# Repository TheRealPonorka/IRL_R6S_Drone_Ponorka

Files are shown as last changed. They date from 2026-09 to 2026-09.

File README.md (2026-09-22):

# Tom Clancy's Rainbow Six: Siege - Recon Drone by Ponorka
Last update: 22/09/2026

This project is inspired by a fictional tool called Recon drone from game Tom Clancy's Rainbow Six: Siege.
I have created a fan page on facebook for this project, where I will post some updates while I am working on it or doing some stuffs with it, here:
https://www.facebook.com/profile.php?id=61594372602997

I have built a similar drone, which was based on another github project https://github.com/hemrobotics/recon-drone and I was wondering: "Can this drone be really a fully operational 2 wheeled remote controlled drone?" This github repo should be the answer for this.

# WIP - Work In Progress
This repo is still in progress. Right now 22/09/2026 the PCB is ready and I am waiting for the supplies so I can build the prototype.
The firmware is mostly ready, but it needs polishing.
Unfortunately, my experience in coding other than PowerShell is HIGHLY LIMITED, so I apologize from everyone who might check the code and see what is happening there :D
So a lot of AI coding will be involved in this project. Sorry to everyone, I am just an enthusiast gamer in this case. In my professional life I am a SysAdmin :D

Slowly but there will be updates here to add the details about this project.

# Make it but don't sell it!
Keep in mind that this is a hobby project and I am giving it available to everyone, who is interested to build this project. So far I am not planning to make money from this and I would be happy to keep this mindset in a same way for everyone.
Don't make a hustle from this project! If you are interested, but you can't build it by yourself, ask someone, give the person all the necessary HW and pay him for the worktime, but do not sell it for profit!
I have applied proper licensing description for this reason.
If you will assemble it, credit my github/facebook fan page properly so others can reach this project as well :)
Thanks for understanding.

# Now the "FUN" Part
Okay, so if you came to this place, you probably want to build your own Recon drone (or maybe just get an inspiration, I don't know, I can't read minds :D ).
I will do my best to explain everything around so the build would be easier to complete for anyone :)

The schematics and Parts
Took me some time to get back to this knowledge, as I did not work on any electronics for several years. I figured out some basic stuffs, which were needed in addition to properly have all the stuffs working together.
As I wanted to add all the possible features what a recon drone have in R6S, I needed think over, what I want to achieve:
1. Self-balancing 2 wheeled robot
2. Camera for reconnaissance
3. LED Spotlight to light up darker places
4. Addressable RGB LED strip with 6 LEDs to replicate the visuals of the drone
5. Operate the entire drone from a single 18650 Li-Po battery cell.
6. Microphone to hear via the web stream what is happening arround. (Unfortunately could not achieve this, so I dropped this feature)

So, how to achieve that?
First we need a microcontroller (MCU) robust enough to handle all the stuffs. After reviewing all the possibilities and cost effectiveness, I decided to go with ESP32-S3 CAM DEVKITC especially from GOOUUU.
For now this is sufficient for everything we need (later on I might rethink the schematics and PCB layout with fully self-built PCB using only the MCU and not the devkit).
For camera module I decided to go with OV3660, as this module has good enough resolution, while keeping the FPS high enough to have a smooth experience.
Early build I planned with omnidirectional microphone module as well, however after further testing this came out as unusable for real time audio stream so I left this idea out of the final build.
The motors I have selected are N20 small geared motors operating on 6V with gear reduction 1:30 and built-in HAL encoder. This gives the drone possibly enough torque and power to balance, while keeping the voltage on lower side (more on it later)
The motor driver is a DRV8833, there is not much to talk about it, it is a sweet spot for this build. Low cost, low power.
The balancing is solved by IMU module BMI270, slotted on the main board.
Now here comes the power consumption part. In my previous attempt to build this drone I was happy to handle everything with only one 18650 LiPo battery cell and I wanted to keep it that way.
I have found a 18650 battery cell shield, which can handle massive current delivery at 5V (up to 3A): https://www.aliexpress.com/item/1005006252337213.html
With this solution I can easily power the ESP32, the LED strip, the motor drivers and the HAL sensors. It might not be able to run for tens of hours, but this solution should be sufficient to handle power delivery for several hours.
The battery shield needed some modifications:
- removed USB-A port
- Removed USB-C charging port and soldered cables for external USB-C connector. This was necessary to add the USB-C charging port on the back of the drone, next to the ON/OFF switch and Wi-Fi antenna.
And if you have a spare 18650 battery cell, you can replace it whenever you need inside chasis. Even though I do not recommend it, as replacement of the battery needs quite some screws to remove. This is something I did not solve in easier way yet.
There was a need to lower voltage from the motors HAL sensors. As they are operating on 5V from the battery shield, but this voltage would fry the MCU, as the MCU operates the GPIO pins with 3.3V. I needed to add a 4-channel bi-polar level shifter, so we don't fry our MCU with 5V input :)
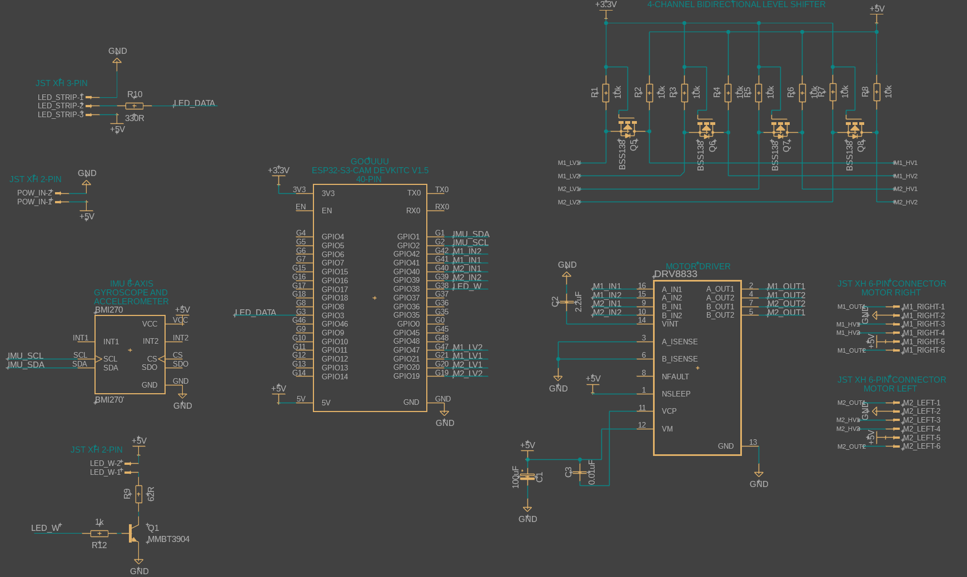
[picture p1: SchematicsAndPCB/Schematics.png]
Schematics


The PCB
After several iterations of how and where the parts should be placed, I finished with this version of 2-layer PCB. The entire PCB size is 45x99.2 mm.

Already ordered PCB from manufacturer
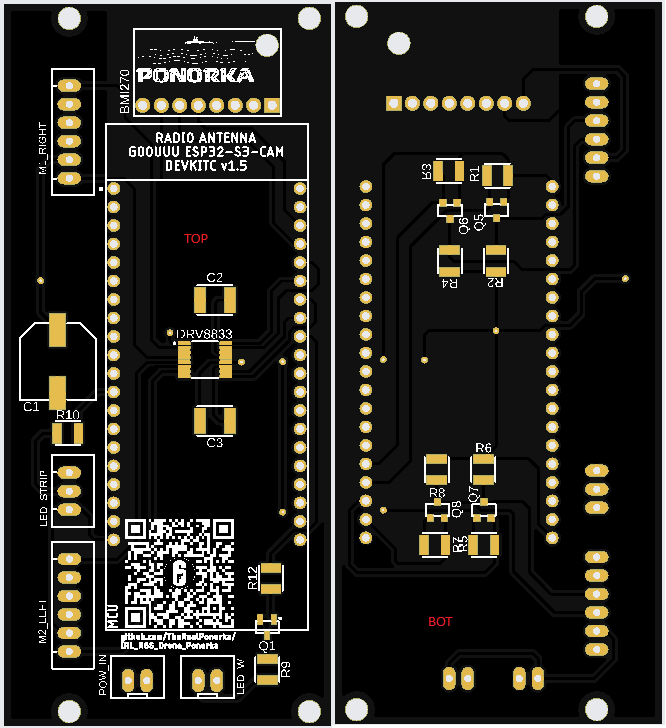
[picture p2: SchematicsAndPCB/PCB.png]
PCB


3D overview of the final board
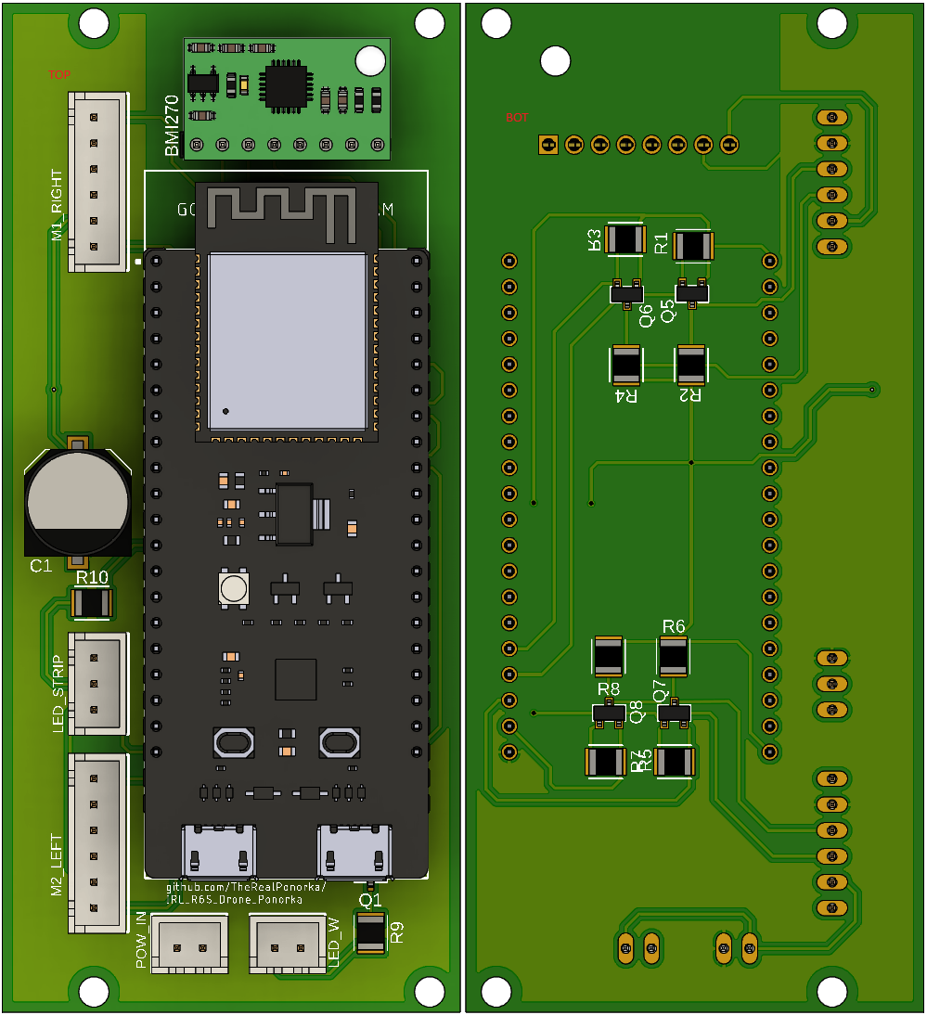
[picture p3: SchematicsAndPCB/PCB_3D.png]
PCB_3D


# The Code
This is where my knowledge is really behind, and if you will review my code later on, you might find a lot of issues with that.
The entire firmware code is based on vide coding in cooperation with Cursor. At the beginning I used Claude Sonnet 4, then I changed it to Cursor Grok 4.6
Right now, the firmware is functioning with these features on test breadboard:
- LED strip is creating the animation of the 6 ARGB LEDs based on the calculation from recorded footage of 30ms from middle to outside and back, default color is GREEN.
- Spotlight high brightness single white LED can be toggled ON/OFF
- Motors are spinning
- IMU is correctly communicating with MCU and based on the tilt it is regulating the motor movement
- MCU Wi-Fi module is correctly generating AP with SSID: "R6_Recone_Drone" and WPA password: "ReconDrone123"
- A basic (so far not modified) webserver is generated by the MCU on IP 192.168.4.1 with camera stream and buttons to operate the drone (move, LED strip color change, LED spotlight toggle, IMU data)

# The Body
I took screenshots from the game and based on it I tried to model out the outside of the drone as accurate as I could.
The body is created from 4 parts:
- TOP
- BOTTOM
- RIGH and LEFT motor/wheel holder
IT IS NOT PERFECTLY ACCURATE.
There were some challenges which I had to solve during initial test prints so it could be printed easier on 3D printer and assemble at the end.
From the front part it looks almost identical to one in the game, however the back I had to change a bit.
The top part on the back is stripped a bit, which I added for the bottom. The reason is to assemble easier the insides: USB-C charging port, Wi-Fi antenna and ON/OFF switch together with the electronics boards inside.
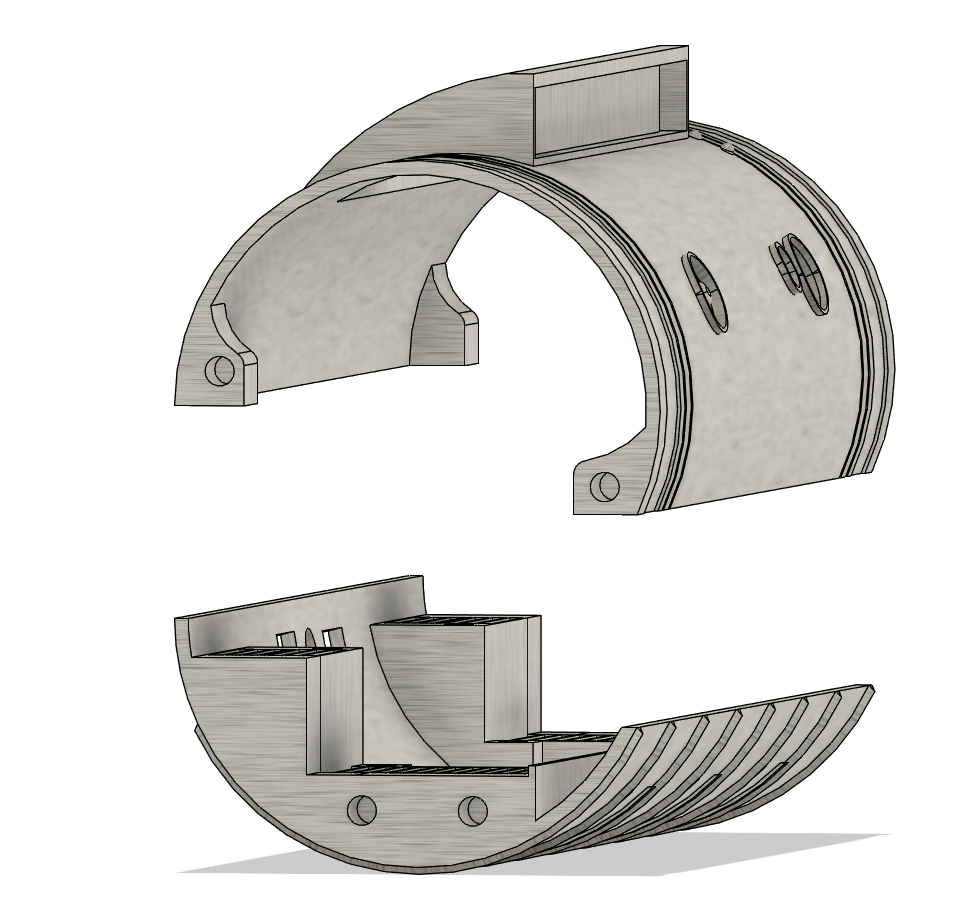
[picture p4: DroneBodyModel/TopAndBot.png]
bodyTopAndBot

The motors I used are the following: https://www.aliexpress.com/item/1005012449655687.html with these specifications selected: "1 to 30, DC 6V A06 Type" and they are screwed in with really small 1.6mm screws
I have created an overengineered stand for this, you can see it on the pictures and the model.

# The test
I know, the breadboard "spaghetti" looks terrifying, but if you follow the schematics, you don't need to be afraid of it :) It is easier than you think!
Anyway, after many attempts, I have finally reached the testing state, where I can (hopefully) confidently say: IT WORKS!

# Next steps
Currently I am waiting for my final PCB (this is my 4th attempt, so my 4th order. I know I f-ed up. I did not start with breadboard testing before I ordered previous PCB attemtps) I have ordered, based on the gerber file you can find in "SchematicsAndPCB"
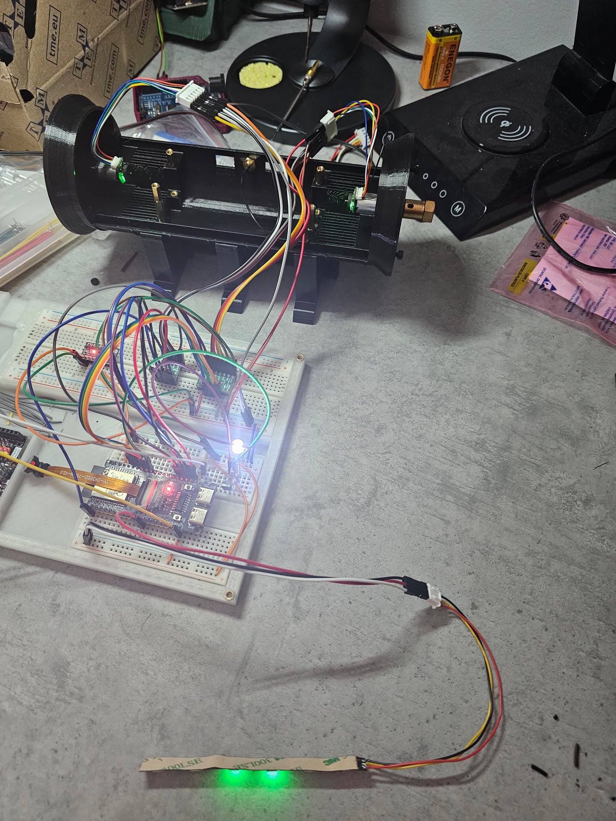
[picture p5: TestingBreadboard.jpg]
Breadboard

Hopefully, once it will arrive and solder all the components (Bill of materials, a.k.a. BOM you can find in "SchematicsAndPCB") it will finally work. Previous (3rd) version was already working, but I connected one motor signal to a PIN, which is used for Wi-Fi, so I had to redo the pinouts a bit.

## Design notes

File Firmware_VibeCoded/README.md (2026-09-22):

# R6 Recon Drone - Rainbow Six: Siege Replica

A fully functional self-balancing camera drone replica inspired by the recon drones from Tom Clancy's Rainbow Six: Siege. Built with ESP32-S3 and featuring a responsive web interface, real-time camera streaming, and advanced control systems.

## 🎯 Features

### Hardware
- **MCU**: ESP32-S3 CAM N16R8 (GOOUUU v1.5) - 16MB Flash, 8MB PSRAM
- **IMU**: BMI270 6-axis sensor for precise balance control
- **Motors**: Dual DRV8833 H-bridge motor controller
- **Camera**: OV3660 with HD 1280x720 default resolution
- **Audio**: INMP441 I2S digital microphone
- **Lighting**: WS2812B RGB LED strip (12 LEDs)
- **Spotlight**: High-power LED with PWM control
- **Encoders**: Quadrature encoders for precise movement tracking

### Software Architecture
- **Dual-Core FreeRTOS**: 
  - Core 0: High-speed IMU/PID balance control at 100Hz
  - Core 1: Web server, camera streaming, LED animations
- **Real-time PID Control**: Advanced balancing algorithms
- **Responsive Web Interface**: Multi-touch support, mobile-optimized
- **Live Camera Streaming**: HD video with configurable settings
- **WiFi Connectivity**: Station mode with AP fallback

### Control Features
- **Movement Controls**: Forward, backward, left, right with smooth acceleration
- **Camera Stream**: Real-time HD video with overlay controls
- **Audio Streaming**: Live microphone feed (when enabled)
- **LED Control**: RGB color picker with animations and patterns
- **Spotlight Control**: Variable brightness white LED
- **Emergency Safety**: Automatic tilt detection and motor cutoff

## 🛠️ Hardware Setup

### Pin Configuration

| Component | Pin Assignment |
|---|---|
| **BMI270 IMU (I2C)** | SCL=1, SDA=2 |
| **DRV8833 Motors** | Motor A: 35,36 / Motor B: 37,38 |
| **Encoders** | Left: 45,46 / Right: 48,21 |
| **INMP441 Microphone** | SCK=41, WS=42, SD=20 |
| **WS2812B LEDs** | Data=3 |
| **Spotlight** | Gate=14 |
| **OV3660 Camera** | SIOD=4, SIOC=5, VSYNC=6, HREF=7, PCLK=13, XCLK=15 |
| **Camera Data** | D0-D7: [11,9,8,10,12,18,17,16] |

### Wiring Diagram
```
ESP32-S3 CAM N16R8
├── I2C Bus (IMU)
│   ├── SCL (GPIO 1) ──→ BMI270 SCL
│   └── SDA (GPIO 2) ──→ BMI270 SDA
├── Motor Control
│   ├── GPIO 35 ──→ DRV8833 Motor A1
│   ├── GPIO 36 ──→ DRV8833 Motor A2  
│   ├── GPIO 37 ──→ DRV8833 Motor B1
│   └── GPIO 38 ──→ DRV8833 Motor B2
├── LED & Lighting
│   ├── GPIO 3 ──→ WS2812B Data In
│   └── GPIO 14 ──→ Spotlight Gate
└── Audio & Sensors
    ├── I2S (GPIO 41,42,20) ──→ INMP441
    └── Encoders (GPIO 45,46,48,21)
```

## 🚀 Quick Start

### 1. PlatformIO Setup
```bash
# Clone the repository
git clone <repository-url>
cd IRL_R6_Drone

# Install PlatformIO (if not already installed)
pip install platformio

# Build the project
pio run

# Upload to ESP32-S3
pio run --target upload

# Monitor serial output
pio device monitor
```

### 2. WiFi Configuration
1. Power on the drone
2. Connect to WiFi network "R6_Drone_Network" (password: "Rainbow6Siege")
3. Or modify `config.h` with your WiFi credentials
4. Access the web interface at the drone's IP address

### 3. Web Interface Access
- **Main Control**: `http://[drone-ip]/`
- **Camera Config**: `http://[drone-ip]/camera-config.html`
- **WebSocket**: `ws://[drone-ip]:81`

## 🎮 Web Interface Guide

### Main Control Interface
- **Camera Stream**: Central HD video feed with overlay controls
- **Movement**: Touch-friendly directional buttons (Forward/Back/Left/Right)
- **Audio**: Microphone toggle in top-right overlay
- **Spotlight**: LED spotlight toggle in bottom-center overlay
- **LED Strip**: Color picker and on/off toggle in bottom-left
- **Fullscreen**: Expand interface to full screen
- **Telemetry**: Real-time sensor data display

### Camera Configuration
- **Resolution**: From 96x96 to 1920x1080 (FHD)
- **Quality**: JPEG compression settings
- **Image Enhancement**: Brightness, contrast, saturation
- **Special Effects**: Filters and color adjustments
- **Presets**: Quick configurations (Recon, Night Vision, High Quality, Performance)

### Control Commands
```javascript
// WebSocket command format
{
  "command": "forward|backward|left|right|microphone|spotlight|ledstrip|ledcolor",
  "value": true|false|"255,140,0",
  "timestamp": 1234567890
}
```

## 🔧 Configuration

### PID Tuning
Edit `config.h` to adjust PID parameters:
```cpp
// Balance PID (pitch control)
#define PID_BALANCE_KP 30.0f
#define PID_BALANCE_KI 0.5f
#define PID_BALANCE_KD 0.8f

// Velocity PID (speed control)  
#define PID_VELOCITY_KP 2.0f
#define PID_VELOCITY_KI 0.1f
#define PID_VELOCITY_KD 0.05f
```

### Camera Settings
```cpp
#define CAMERA_FRAME_SIZE FRAMESIZE_HD    // 1280x720
#define CAMERA_QUALITY 10                 // JPEG quality
#define CAMERA_FB_COUNT 2                 // Frame buffers
```

### Performance Tuning
```cpp
#define PID_LOOP_FREQUENCY_HZ 100         // Control loop speed
#define CAMERA_STREAM_FPS 30              // Video frame rate
#define LED_ANIMATION_UPDATE_MS 50        // LED refresh rate
```

## 📡 System Architecture

### FreeRTOS Task Distribution
| Core | Task | Priority | Stack | Frequency |
|---|---|---|---|---|
| 0 | IMU + PID + Motors | Critical | 4KB | 100Hz |
| 1 | Web Server | Medium | 6KB | Variable |
| 1 | Camera Stream | High | 8KB | 30FPS |
| 1 | LED Animation | Low | 2KB | 20Hz |
| 1 | Audio Process | Medium | 4KB | 50Hz |

### Data Flow
```
IMU Sensor → PID Controller → Motor PWM
     ↓              ↓
WebSocket ← Web Interface ← Camera Stream
     ↓
LED Controller + Audio Stream
```

## 🔒 Safety Features

- **Tilt Protection**: Emergency stop at ±45° tilt angle
- **Command Timeout**: Auto-stop after 2 seconds without commands
- **Watchdog Timer**: System reset on 5-second freeze
- **WiFi Monitoring**: Connection status indicators
- **Battery Monitoring**: Low voltage detection (if connected)

## 🎨 LED Patterns

| Pattern | Description | Trigger |
|---|---|---|
| Startup | Rainbow wipe | Boot sequence |
| Solid | User color | Normal operation |
| Breathing | Pulsing | Balancing mode |
| Emergency | Red strobe | Tilt detection |
| R6 Theme | Orange/Blue chase | Rainbow Six colors |

## 🐛 Troubleshooting

### Common Issues

**IMU Calibration Failed**
```
- Check I2C connections (GPIO 1,2)
- Ensure drone is level during startup
- Verify BMI270 power supply
```

**Camera Not Streaming**
```
- Check camera module connection
- Verify DVP pin assignments
- Restart with camera disconnected, then reconnect
```

**Motors Not Responding**
```
- Verify DRV8833 connections
- Check motor power supply
- Ensure emergency stop is not active
```

**Web Interface Not Loading**
```
- Confirm WiFi connection
- Check IP address in serial monitor
- Try AP mode if STA fails
```

### Debug Commands
```cpp
// Enable debug output
#define DEBUG_ENABLED true
#define CURRENT_LOG_LEVEL LOG_LEVEL_DEBUG

// Performance monitoring
#define PERFORMANCE_MONITORING true
#define MEMORY_MONITOR_ENABLED true
```

## 📈 Performance Optimization

### Memory Usage
- **Heap**: ~200KB free (of 320KB)
- **PSRAM**: ~7MB available for camera buffers
- **Flash**: ~14MB available for web assets and OTA

### CPU Utilization
- **Core 0**: 60-80% (PID control loop)
- **Core 1**: 40-60% (web server + camera)

## 🔄 OTA Updates

```bash
# Upload via WiFi (change IP address)
pio run -e esp32s3_r6drone_ota --target upload --upload-port 192.168.1.100
```

## 📝 License

This project is licensed under the MIT License. See `LICENSE` file for details.

## 🤝 Contributing

1. Fork the repository
2. Create a feature branch
3. Commit your changes
4. Push to the branch
5. Create a Pull Request

## 🎖️ Credits

- **Author**: Peter
- **Inspired by**: Tom Clancy's Rainbow Six: Siege
- **ESP32 Framework**: Espressif Systems
- **Libraries**: See `platformio.ini` for full list

## 📞 Support

For issues, questions, or contributions:
1. Check the troubleshooting section
2. Review existing GitHub issues
3. Create a new issue with detailed information
4. Include serial monitor output for debugging

---

**⚠️ Safety Warning**: This drone contains spinning motors and electronic components. Always operate in a safe environment, keep fingers away from moving parts, and ensure proper battery handling. The emergency stop (spacebar) should always be accessible during operation.

**🎯 Have fun recreating the tactical recon experience from Rainbow Six: Siege!**

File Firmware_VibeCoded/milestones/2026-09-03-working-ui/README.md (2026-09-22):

# Milestone: working recon UI (3 Sep 2026)

Frozen working firmware. Restore this before adding motors or other features.

## Build

- PlatformIO env: `esp32s3_simple_test`
- Source file: `src/main_camera_stream.cpp`
- Git tag (if repo exists): `milestone-2026-09-03-working-ui`

## Working features

- OV3660 latest-frame JPEG view (HVGA 480x320, shown in a 16:9 box)
- BMI270 pitch / roll / yaw on the web page (`/imu`)
- WS2812B 6-LED middle-out animation
- LED on/off toggle
- LED color picker (all LEDs same RGB)
- Spotlight on/off
- Wi-Fi AP `R6_Recon_Drone` / `ReconDrone123`
- Web UI: `http://192.168.4.1`

## Intentionally not in this milestone

- INMP441 microphone (removed)
- Motor drive / PID balancing
- Encoders
- HD camera (quality traded for low delay)

## How to restore

1. Check out tag `milestone-2026-09-03-working-ui`, or copy files from `milestones/2026-09-03-working-ui/`
2. Build and upload `esp32s3_simple_test`

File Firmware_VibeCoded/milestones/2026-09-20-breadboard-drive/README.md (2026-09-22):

# Milestone: breadboard drive (20 Sep 2026)

Frozen copies of the working breadboard firmware.

See the repo-root `MILESTONE.md` for the full lock notes, GPIO table, and restore steps.

- Env: `esp32s3_simple_test`
- Tag: `milestone-2026-09-20-breadboard-drive`
- Files here: `main_camera_stream.cpp`, `config.h`, `platformio.ini`

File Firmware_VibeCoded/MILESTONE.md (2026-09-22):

# Milestone: breadboard drive (20 Sep 2026)

Frozen working firmware after the breadboard bring-up. Restore this before PID self-balance, core split changes, or other large features.

Previous lock (camera/LED/IMU/spotlight only): `milestone-2026-09-03-working-ui` and `milestones/2026-09-03-working-ui/`.

## Build

- PlatformIO env: `esp32s3_simple_test`
- Source file: `src/main_camera_stream.cpp`
- Git tag: `milestone-2026-09-20-breadboard-drive`
- Upload over **TTL USB-C (CH340) only**. Do not plug OTG USB-C (encoders sit on GPIO 19/20).

## Working features

- OV3660 latest-frame JPEG view (HVGA 480x320)
- BMI270 pitch / roll / yaw
- WS2812B 6-LED animation, on/off, RGB color picker
- Spotlight on/off
- Hold-to-drive FWD / BACK / LEFT / RIGHT (web pad + WASD / arrows)
- DRV8833 PWM on both motor channels (idle pin forced LOW, 5 kHz)
- Hall encoder counts on the web status line
- Wi-Fi AP `R6_Recon_Drone` / `ReconDrone123`
- Web UI: `http://192.168.4.1`

## Locked GPIO map

| Feature | GPIO |
|---|---|
| IMU SDA / SCL | 1 / 2 |
| LED strip DIN | 3 |
| Spotlight | 38 |
| Motor A AIN1 / AIN2 | 41 / 42 |
| Motor B BIN1 / BIN2 | 39 / 40 |
| Left encoder A / B | 19 / 20 |
| Right encoder A / B | 21 / 47 |
| Camera DVP | 4, 5, 6, 7, 8, 9, 10, 11, 12, 13, 15, 16, 17, 18 |

Motor LEDC channels: 2, 3, 4, 5 (camera XCLK stays on 0, spotlight on 7).

## Known hardware note

- One physical motor on the breadboard is faulty. Swapping motors between driver outputs confirmed the firmware and both DRV8833 channels are good. Replace that motor; no pin change required.

## Intentionally not in this milestone

- PID / self-balancing (unsafe until both motors are healthy)
- Dual-core 100 Hz balance loop (still camera/LED/IMU on core 0, HTTP on core 1)
- INMP441 microphone (removed)
- HD camera (quality traded for low delay)

## How to restore

1. Check out tag `milestone-2026-09-20-breadboard-drive`, or copy files from `milestones/2026-09-20-breadboard-drive/`
2. Build and upload `esp32s3_simple_test`

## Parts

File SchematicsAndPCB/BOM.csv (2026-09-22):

Reference Designators | Quantity | Description | Package | Value | Manufacturer | Manufacturer Part Number | Vendor | Vendor Part Number | Top/Bottom
U1 | 1 | IMU | 1line 7-pin daughter board | BMI270 | https://www.aliexpress.com/item/1005012475229129.htm |  |  |  | Top
C1 | 1 | Capacitor Polarised - Generic | CAPAE1030X1050N | 100uF |  |  |  |  | Top
C2 | 1 | Capacitor - Generic | CAPC4532X135 | 2.2uF |  |  |  |  | Top
C3 | 1 | Capacitor - Generic | CAPC4532X135 | 0.01uF |  |  |  |  | Top
U2 | 1 | Motor driver | HTSSOP16 | DRV8833PWP | Texas Instruments |  |  |  | Top
LED_STRIP | 1 | JST XH Connector 2 Pin | JST-XH-03-PACKAGE-LONG-PAD |  |  |  |  |  | Top
LED_W | 1 | JST XH Connector 2 Pin | JST-XH-02-PACKAGE-LONG-PAD |  |  |  |  |  | Top
POW_IN | 1 | JST XH Connector 2 Pin | JST-XH-02-PACKAGE-LONG-PAD |  |  |  |  |  | Top
M1_RIGHT, M2_LEFT | 2 | JST XH Connector 6 Pin | JST-XH-06-PACKAGE-LONG-PAD |  |  |  |  |  | Top
U3 | 1 | MCU | 2 line 40-pin devkit board | GOOUUU-ESP32-S3-CAM-DEVKITC | https://www.aliexpress.com/item/1005008568072063.html |  |  |  | Top
Q1 | 1 | NPN Transistor - Popular parts | SOT95P237X112-3N | MMBT3904 |  | MMBT3904-7-F |  |  | Top
Q5, Q6, Q7, Q8 | 4 | N-Channel MOSFET - Popular parts | SOT23 | BSS138 |  |  |  |  | Bottom
R1, R2, R3, R4, R5, R6, R7, R8 | 8 | Resistor Fixed - Generic | RESC3224X71 | 10k |  |  |  |  | Bottom
R9 | 1 | Resistor Fixed - Generic | RESC3224X71 | 62R |  |  |  |  | Top
R10 | 1 | Resistor Fixed - Generic | RESC3224X71 | 330R |  |  |  |  | Top
R12 | 1 | Resistor Fixed - Generic | RESC3224X71 | 1k |  |  |  |  | Top

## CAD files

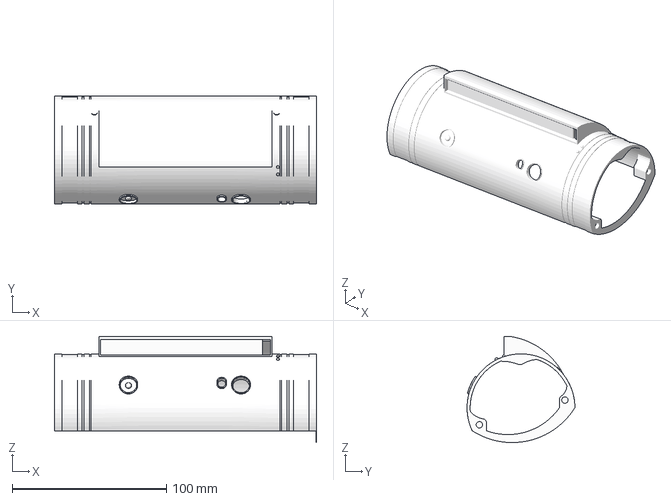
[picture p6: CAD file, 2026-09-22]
DroneBodyModel/main top.3mf
170.0 x 70.0 x 68.8 mm

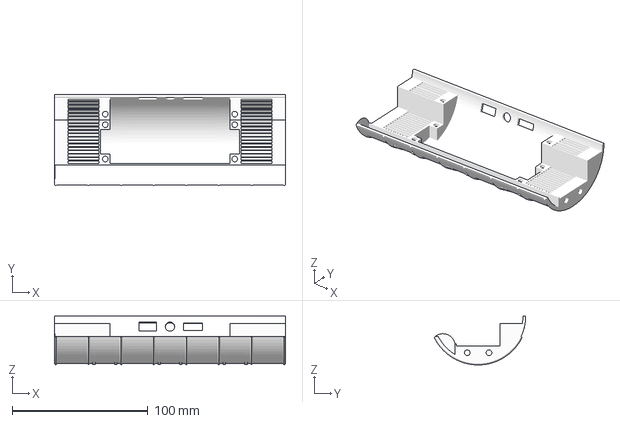
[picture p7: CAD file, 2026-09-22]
DroneBodyModel/main bottom.3mf
170.0 x 67.3 x 36.0 mm

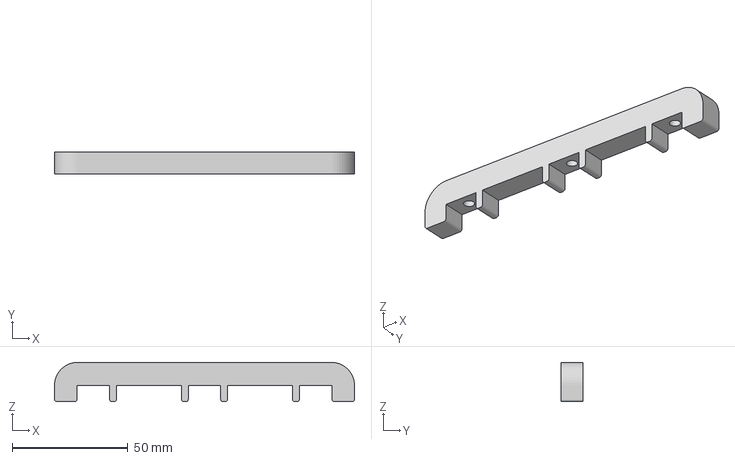
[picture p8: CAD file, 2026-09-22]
DroneBodyModel/standConnect.3mf
129.6 x 9.60 x 17.0 mm

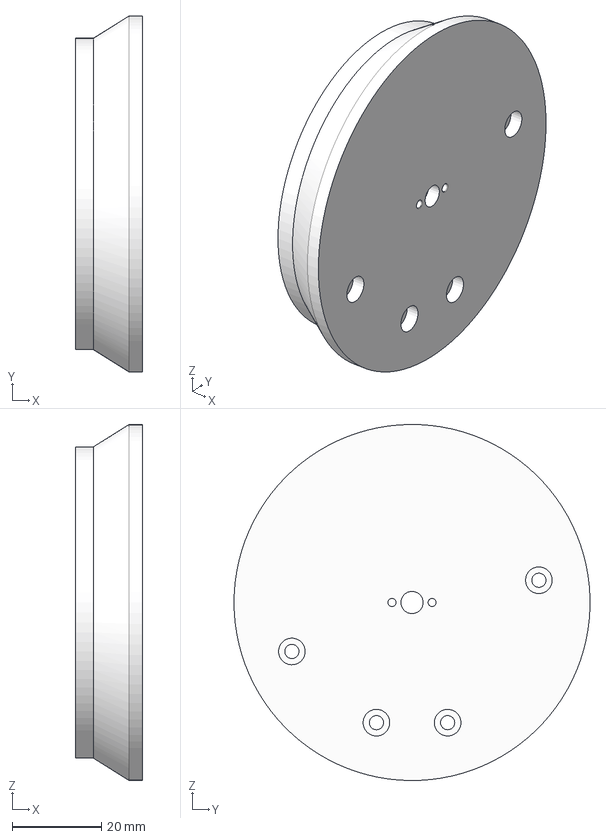
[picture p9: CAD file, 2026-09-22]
DroneBodyModel/motor holder right.3mf
15.0 x 80.0 x 80.0 mm

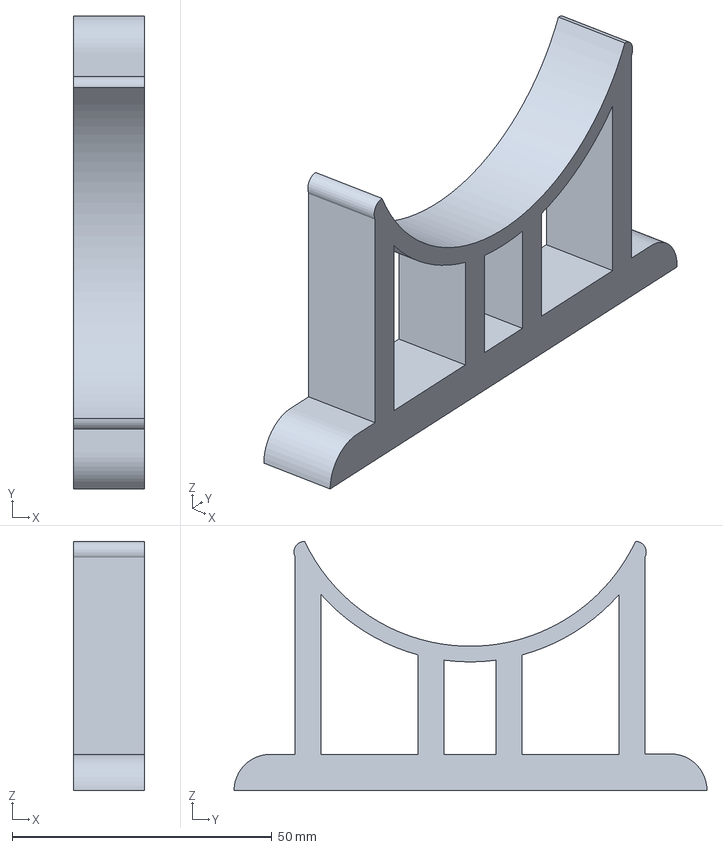
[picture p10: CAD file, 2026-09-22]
DroneBodyModel/standLegMid.3mf
13.6 x 91.1 x 48.0 mm

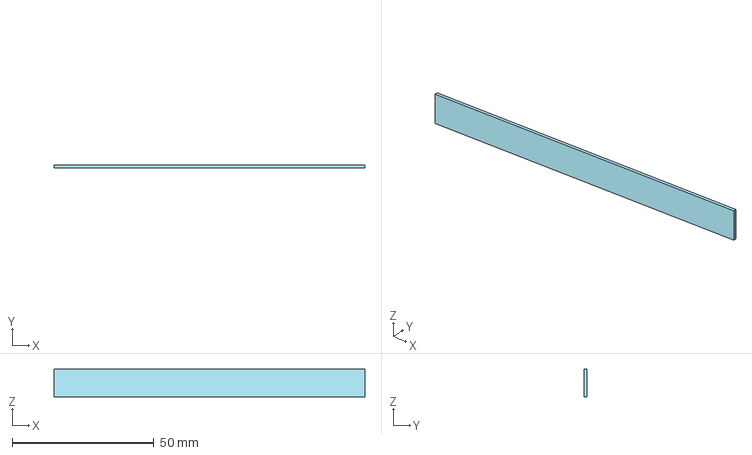
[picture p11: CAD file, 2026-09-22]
DroneBodyModel/LED difuser.3mf
109.8 x 1.00 x 9.80 mm

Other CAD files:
DroneBodyModel/standLegRight.3mf
DroneBodyModel/standLegLeft.3mf
DroneBodyModel/motor holder left.3mf

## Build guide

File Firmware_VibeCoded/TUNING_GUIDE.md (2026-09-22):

# 🎯 Drone Tuning and Calibration Guide

This guide will walk you through the essential steps to calibrate your IMU sensor and tune the PID controller for optimal self-balancing performance.

## 📋 Prerequisites

Before starting, ensure you have:
- ✅ All hardware properly connected according to the wiring diagram
- ✅ Code uploaded to the ESP32-S3
- ✅ Serial monitor access (PlatformIO or Arduino IDE)
- ✅ A flat, level surface for testing
- ✅ Safety glasses (motors can spin fast!)

## 🔧 Part 1: IMU Calibration

### What is IMU Calibration?
The BMI270 sensor needs to know its "zero" position when the drone is perfectly level. This removes sensor bias and drift for accurate balance detection.

### Step-by-Step IMU Calibration

#### 1. **Prepare the Drone**
```bash
# Open serial monitor first
pio device monitor
# OR use Arduino IDE Serial Monitor at 115200 baud
```

#### 2. **Position the Drone**
- Place drone on a **completely flat surface** (use a spirit level if available)
- Ensure the drone is **not moving at all**
- Keep the area **vibration-free** (no walking around, no washing machine running)

#### 3. **Power On and Observe**
When you power on, you should see output like:
```
=================================
Rainbow Six: Siege Recon Drone
Firmware Version: 1.0.0
=================================
Initializing BMI270 IMU...
Calibrating BMI270...
Calibration progress: 0/1000
Calibration progress: 100/1000
Calibration progress: 200/1000
...
Calibration progress: 900/1000
Gyro offsets: X=-1.234, Y=0.567, Z=-0.123
Accel offsets: X=0.045, Y=-0.012, Z=0.023
BMI270 calibration complete
```

#### 4. **Calibration Success Indicators**
✅ **Good calibration**: Offset values between -5.0 and +5.0  
❌ **Poor calibration**: Offset values > ±10.0 or calibration fails

#### 5. **If Calibration Fails**
```cpp
// Troubleshooting steps:
1. Check I2C connections (GPIO 1, 2)
2. Verify BMI270 power supply (3.3V)
3. Ensure drone is completely still
4. Try different surface (more level)
5. Restart and try again
```

### Manual Re-calibration
If you need to recalibrate later, there are several options:

#### Option A: Automatic on Startup (Default)
- Simply restart the drone on a level surface
- Calibration runs automatically each boot

#### Option B: Web Interface Calibration (Future Feature)
We can add a calibration button to the web interface if needed.

#### Option C: Serial Commands (Advanced)
```cpp
// Add this to your serial monitor while drone is running
CALIBRATE_IMU
```

## 🎮 Part 2: PID Tuning

### What is PID Control?
PID stands for:
- **P**roportional: How hard to push back when tilted
- **I**ntegral: Corrects for steady-state errors over time  
- **D**erivative: Dampens oscillations and overshooting

### Understanding the Three PID Controllers

Your drone has **three separate PID controllers**:

#### 1. **Balance PID** (Most Important)
```cpp
// In config.h - these control the main balancing
#define PID_BALANCE_KP 30.0f    // Proportional gain
#define PID_BALANCE_KI 0.5f     // Integral gain  
#define PID_BALANCE_KD 0.8f     // Derivative gain
```
**Purpose**: Keeps the drone upright (pitch control)

#### 2. **Velocity PID** 
```cpp
#define PID_VELOCITY_KP 2.0f    // Forward/backward movement
#define PID_VELOCITY_KI 0.1f    
#define PID_VELOCITY_KD 0.05f   
```
**Purpose**: Controls forward/backward movement smoothness

#### 3. **Position PID**
```cpp
#define PID_POSITION_KP 1.5f    // Left/right turning
#define PID_POSITION_KI 0.0f    
#define PID_POSITION_KD 0.1f    
```
**Purpose**: Controls turning and rotation

### Step-by-Step PID Tuning Process

#### Phase 1: Safety Setup
1. **Prepare Testing Area**
   - Clear 3x3 meter space minimum
   - Soft surface (carpet or foam mats)
   - Remove breakable objects
   - Have emergency stop ready (spacebar in web interface)

2. **Initial Test Position**
   - Hold drone in your hands initially
   - Feel the motor response
   - Check that motors spin in correct directions

#### Phase 2: Basic Balance Tuning

**Start with Conservative Values:**
```cpp
// In config.h - start with these SAFE values
#define PID_BALANCE_KP 10.0f    // Start low!
#define PID_BALANCE_KI 0.0f     // Disable integral first
#define PID_BALANCE_KD 0.2f     // Start low!
```

**Tuning Process:**

1. **Test Kp (Proportional) First**
   ```cpp
   // Step 1: Start with Kp=5, Ki=0, Kd=0
   // Gently tilt drone - does it try to correct?
   
   // If NO response: Increase Kp by 5
   // If WEAK response: Increase Kp by 2-3
   // If STRONG response but oscillates: Decrease Kp
   // If VIOLENT oscillation: EMERGENCY STOP, lower Kp significantly
   ```

2. **Add Kd (Derivative) for Stability**
   ```cpp
   // Step 2: Once Kp gives decent correction, add Kd
   // Start with Kd = Kp / 20
   // Example: If Kp=20, try Kd=1.0
   
   // Too much oscillation: Increase Kd
   // Too sluggish: Decrease Kd
   // Good balance but slight bounce: Fine-tune both
   ```

3. **Fine-tune Ki (Integral) Last**
   ```cpp
   // Step 3: Add Ki only if drone drifts when "balanced"
   // Start with Ki = Kp / 100
   // Example: If Kp=20, try Ki=0.2
   
   // Ki too high: Oscillation and instability
   // Ki too low: Slow drift correction
   ```

#### Phase 3: Real-World Testing

**Progressive Testing:**

1. **Hand Testing**
   - Hold drone, tilt gently, observe correction
   - Should feel like it "wants" to stay level
   - No violent jerking or continuous buzzing

2. **Table Edge Testing**  
   - Place on table edge (safely!)
   - Let one wheel hang over edge
   - Should balance itself back onto table

3. **Free Balance Testing**
   - Place on flat surface
   - Should stay upright for 10+ seconds
   - Minor adjustments are normal

4. **Movement Testing**
   - Try gentle forward/backward commands
   - Should move smoothly without face-planting
   - Should stop and balance when released

### 🔍 Troubleshooting Common Issues

#### Problem: Violent Oscillation
```cpp
// Solution: Reduce Kp dramatically
#define PID_BALANCE_KP 5.0f     // Was too high
#define PID_BALANCE_KD 0.5f     // Add more damping
```

#### Problem: No Response to Tilt
```cpp
// Solution: Check motor directions and increase Kp
// Verify motors spin correct direction for correction
#define PID_BALANCE_KP 25.0f    // Increase response
```

#### Problem: Balances but Drifts
```cpp
// Solution: Add integral term
#define PID_BALANCE_KI 0.3f     // Correct steady-state error
```

#### Problem: Unstable at Speed
```cpp
// Solution: Tune velocity PID
#define PID_VELOCITY_KP 1.0f    // Reduce for smoother movement
#define PID_VELOCITY_KD 0.1f    // Add damping
```

### 📊 Tuning Parameter Ranges

| Parameter | Typical Range | Start Value | Notes |
|---|---|---|---|
| Balance Kp | 5.0 - 50.0 | 15.0 | Most critical parameter |
| Balance Ki | 0.0 - 2.0 | 0.0 | Add last, use sparingly |
| Balance Kd | 0.1 - 5.0 | 0.5 | Prevents oscillation |
| Velocity Kp | 0.5 - 5.0 | 1.5 | Smooth movement |
| Position Kp | 0.5 - 3.0 | 1.0 | Turning response |

## 🚨 Safety Guidelines

### Emergency Procedures
1. **Spacebar** = Emergency stop (web interface)
2. **Power switch** = Ultimate emergency stop
3. **Tilt limit** = 45° automatic stop (already coded)

### Safe Tuning Practices
- ✅ Start with LOW values, increase gradually
- ✅ Test in safe area with soft surfaces  
- ✅ Keep emergency stop accessible
- ✅ Never tune with people nearby
- ✅ Wear safety glasses
- ❌ Don't tune near walls or furniture
- ❌ Don't skip the hand-testing phase
- ❌ Don't increase all parameters at once

## 📈 Advanced Tuning Tips

### Real-Time Tuning (Advanced)
You can modify PID values while running by adding serial commands:

```cpp
// Example serial commands to add to main.cpp:
// "KP:25.0" = Set balance Kp to 25.0
// "KI:0.5"  = Set balance Ki to 0.5  
// "KD:1.2"  = Set balance Kd to 1.2
```

### Data Logging for Analysis
The telemetry shows current values:
- **Pitch angle**: Should stay near 0°
- **Motor speeds**: Should be smooth, not jerky
- **CPU usage**: Should stay under 80%

### Environmental Factors
- **Surface**: Hard floors need different tuning than carpet
- **Weight**: Adding camera/payload affects balance point
- **Battery level**: Lower voltage = less responsive motors
- **Temperature**: Can affect sensor readings slightly

## 🎯 Success Criteria

Your drone is properly tuned when:
- ✅ Stays upright on flat surface for 30+ seconds
- ✅ Recovers from gentle pushes smoothly
- ✅ Moves forward/backward without falling
- ✅ Turns left/right controllably
- ✅ No violent oscillations or buzzing
- ✅ Responds to web interface commands reliably

## 🔧 Quick Reference: Tuning Workflow

```bash
1. IMU Calibration (automatic on flat surface)
2. Set conservative PID values
3. Hand test motor response
4. Gradually increase Kp until responsive
5. Add Kd to reduce oscillation
6. Test free balancing
7. Add Ki if needed for drift
8. Test movement commands
9. Fine-tune for your environment
10. Document final values!
```

## 📝 Final Values Template

Once you find good values, document them:

```cpp
// My Final Tuned Values - [Date]
// Surface: [carpet/hardwood/concrete]
// Weight: [total drone weight]
#define PID_BALANCE_KP XX.Xf
#define PID_BALANCE_KI X.Xf  
#define PID_BALANCE_KD X.Xf
#define PID_VELOCITY_KP X.Xf
#define PID_VELOCITY_KI X.Xf
#define PID_VELOCITY_KD X.Xf
// Notes: [what works well, any quirks]
```

## 🆘 Getting Help

If you run into issues:
1. Check serial monitor output for error messages
2. Verify all connections match the wiring diagram
3. Ensure IMU calibration completed successfully
4. Start with very conservative PID values
5. Test each component individually (IMU, motors, encoders)

Remember: **PID tuning is an iterative process**. Don't expect perfection on the first try. Each adjustment teaches you how your specific drone behaves!

Good luck with your R6 Recon Drone! 🚁

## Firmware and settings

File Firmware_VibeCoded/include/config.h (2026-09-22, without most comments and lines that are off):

#define CONFIG_H
#include <Arduino.h>
#define BOARD_MODEL "ESP32-S3 CAM N16R8"
#define BOARD_VERSION "1.5"
#define BOARD_MANUFACTURER "GOOUUU"
#define FLASH_SIZE_MB 16
#define PSRAM_SIZE_MB 8
#define CORE_0_TASKS 0  // High-speed control loop
#define CORE_1_TASKS 1  // Web server and peripherals
#define PRIORITY_CRITICAL 3  // IMU + PID + Motor control
#define PRIORITY_HIGH 2      // Camera streaming
#define PRIORITY_MEDIUM 1    // Web server, LED animations
#define PRIORITY_LOW 0       // Background tasks
#define PID_LOOP_FREQUENCY_HZ 100
#define PID_LOOP_PERIOD_MS (1000 / PID_LOOP_FREQUENCY_HZ)
#define CAMERA_STREAM_FPS 30
#define LED_ANIMATION_UPDATE_MS LED_ANIMATION_SPEED
#define ENCODER_READ_INTERVAL_MS 10
#define IMU_ENABLED true
#define IMU_SDA_PIN 1
#define IMU_SCL_PIN 2
#define IMU_I2C_FREQ 400000  // 400kHz
#define IMU_I2C_PORT 0
#define IMU_ADDRESS 0x68     // BMI270 default address
#define IMU_INT_PIN -1       // Not used for polling mode
#define GYRO_RANGE 2000      // ±2000°/s
#define ACCEL_RANGE 16       // ±16g
#define IMU_FILTER_ALPHA 0.98f  // Complementary filter coefficient
#define GYRO_DEADBAND 2.0f   // Degrees/second deadband
#define MOTORS_ENABLED true
#define MOTOR_A_PIN1 41      // Motor A Forward  (DRV8833 AIN1)
#define MOTOR_A_PIN2 42      // Motor A Reverse  (DRV8833 AIN2)
#define MOTOR_B_PIN1 39      // Motor B Forward  (DRV8833 BIN1)
#define MOTOR_B_PIN2 40      // Motor B Reverse  (DRV8833 BIN2)
#define MOTOR_PWM_FREQ 5000     // 5kHz — 20kHz can trip cheap DRV8833 modules
#define MOTOR_PWM_RESOLUTION 8  // 8-bit resolution (0-255)
#define MOTOR_PWM_CHANNEL_A1 2
#define MOTOR_PWM_CHANNEL_A2 3
#define MOTOR_PWM_CHANNEL_B1 4
#define MOTOR_PWM_CHANNEL_B2 5
#define MOTOR_MAX_SPEED 255
#define MOTOR_MIN_SPEED 0
#define MOTOR_DEADBAND 10    // Minimum PWM to overcome friction
#define ENCODERS_ENABLED true
#define ENCODER_LEFT_A_PIN 19   // Left encoder A  (USB_D+ silkscreen; TTL USB only)
#define ENCODER_LEFT_B_PIN 20   // Left encoder B  (USB_D- silkscreen; TTL USB only)
#define ENCODER_RIGHT_A_PIN 21  // Right encoder A
#define ENCODER_RIGHT_B_PIN 47  // Right encoder B
#define ENCODER_PPR 20          // Pulses per revolution
#define WHEEL_DIAMETER_MM 65    // Wheel diameter in millimeters
#define ENCODER_FILTER_SAMPLES 3 // Moving average filter
#define PID_ENABLED true
#define PID_BALANCE_KP 12.0f
#define PID_BALANCE_KI 0.0f
#define PID_BALANCE_KD 0.45f
#define PID_BALANCE_SETPOINT 0.0f  // Overwritten at warmup / Set level
#define BALANCE_DEADBAND_DEG 3.0f
#define BALANCE_WARMUP_MS 1500
#define PID_VELOCITY_KP 2.0f
#define PID_VELOCITY_KI 0.1f
#define PID_VELOCITY_KD 0.05f
#define PID_POSITION_KP 1.5f
#define PID_POSITION_KI 0.0f
#define PID_POSITION_KD 0.1f
#define PID_OUTPUT_LIMIT 200
#define PID_INTEGRAL_LIMIT 100
#define BALANCE_ANGLE_LIMIT 45.0f  // Degrees - safety cutoff
#define CAMERA_ENABLED true
#define CAMERA_MODEL_OV3660
#define CAM_PIN_SIOD 4    // SDA
#define CAM_PIN_SIOC 5    // SCL
#define CAM_PIN_VSYNC 6   // Vertical sync
#define CAM_PIN_HREF 7    // Horizontal reference
#define CAM_PIN_PCLK 13   // Pixel clock
#define CAM_PIN_XCLK 15   // External clock
#define CAM_PIN_D0 11
#define CAM_PIN_D1 9
#define CAM_PIN_D2 8
#define CAM_PIN_D3 10
#define CAM_PIN_D4 12
#define CAM_PIN_D5 18
#define CAM_PIN_D6 17
#define CAM_PIN_D7 16
#define CAMERA_FRAME_SIZE FRAMESIZE_HD    // 1280x720 default
#define CAMERA_PIXEL_FORMAT PIXFORMAT_JPEG
#define CAMERA_QUALITY 10    // JPEG quality (0-63, lower = better)
#define CAMERA_FB_COUNT 2    // Frame buffer count
#define CAMERA_XCLK_FREQ_HZ 20000000  // 20MHz
#define LED_STRIP_ENABLED true
#define LED_DATA_PIN 3
#define LED_COUNT 6          // Number of LEDs in strip (0-5)
#define LED_BRIGHTNESS 64    // Default brightness (0-255) = 25%
#define LED_TYPE NEO_GRB     // Color order
#define LED_ANIMATION_SPEED 30   // milliseconds between animation steps
#define LED_FADE_STEPS 20
#define LED_RAINBOW_SPEED 5
#define LED_COLOR_OFF 0x000000
#define LED_COLOR_RED 0xFF0000
#define LED_COLOR_GREEN 0x00FF00      // Default startup color
#define LED_COLOR_BLUE 0x0000FF
#define LED_COLOR_WHITE 0xFFFFFF
#define LED_COLOR_R6_ORANGE 0xFF8C00  // Rainbow Six orange theme
#define SPOTLIGHT_ENABLED true
#define SPOTLIGHT_PIN 38     // Gate/Base driver pin
#define SPOTLIGHT_PWM_CHANNEL 7
#define SPOTLIGHT_PWM_FREQ 1000
#define SPOTLIGHT_PWM_RESOLUTION 8
#define SPOTLIGHT_MAX_BRIGHTNESS 255
#define SPOTLIGHT_DEFAULT_BRIGHTNESS 128
#define WIFI_ENABLED true
#define WIFI_CONNECTION_TIMEOUT_MS 10000
#define WIFI_RECONNECT_INTERVAL_MS 5000
#define WIFI_MAX_RECONNECT_ATTEMPTS 10
#define DEFAULT_WIFI_SSID "R6_Drone_Network"
#define DEFAULT_WIFI_PASSWORD "Rainbow6Siege"
#define AP_MODE_ENABLED true
#define AP_SSID "R6_Recon_Drone"
#define AP_PASSWORD "ReconDrone123"
#define AP_CHANNEL 6
#define AP_MAX_CONNECTIONS 4
#define WEBSERVER_ENABLED true
#define WEBSERVER_PORT 80
#define WEBSOCKET_PORT 81
#define MAX_WEBSOCKET_CLIENTS 4
#define STREAM_PART_BOUNDARY "123456789000000000000987654321"
#define WEB_UPDATE_INTERVAL_MS 100
#define CONTROL_TIMEOUT_MS 2000  // Stop motors if no command received
#define DRIVE_HOLD_TIMEOUT_MS 800  // Stop if no drive request arrives (click or hold)
#define BUTTON_DEBOUNCE_MS 50
#define CONTROL_ENABLED true
#define SPEED_FORWARD 150
#define SPEED_BACKWARD 120
#define SPEED_TURN_LEFT 100
#define SPEED_TURN_RIGHT 100
#define SPEED_STOP 0
#define ACCELERATION_RATE 5    // PWM units per update
#define DECELERATION_RATE 8    // PWM units per update
#define TURN_SENSITIVITY 0.7f
#define TILT_SAFETY_ANGLE 60.0f      // Degrees - emergency stop
#define LOW_BATTERY_VOLTAGE 3.2f     // Volts per cell
#define EMERGENCY_STOP_ENABLED true
#define WATCHDOG_TIMEOUT_MS 5000
#define MONITORING_ENABLED true
#define BATTERY_MONITOR_PIN A0  // If available
#define SYSTEM_STATUS_UPDATE_MS 1000
#define TEMPERATURE_MONITOR_ENABLED false  // ESP32-S3 internal temp
#define DEBUG_ENABLED true
#define SERIAL_BAUD_RATE 115200
#define LOG_LEVEL_DEBUG 0
#define LOG_LEVEL_INFO 1
#define LOG_LEVEL_WARN 2
#define LOG_LEVEL_ERROR 3
#define CURRENT_LOG_LEVEL LOG_LEVEL_INFO
#define PERFORMANCE_MONITORING true
#define TASK_MONITOR_INTERVAL_MS 5000
#define MEMORY_MONITOR_ENABLED true
#define FEATURE_AUDIO_STREAMING true
#define FEATURE_OTA_UPDATE true
#define FEATURE_TELEMETRY true
#define FEATURE_GESTURE_CONTROL false  // Future feature
#define FEATURE_AUTONOMOUS_MODE false  // Future feature
#define FEATURE_NIGHT_VISION false     // Future feature
#define STACK_SIZE_CONTROL_TASK 4096
#define STACK_SIZE_CAMERA_TASK 8192
#define STACK_SIZE_WEB_TASK 6144
#define STACK_SIZE_LED_TASK 2048
#define STACK_SIZE_AUDIO_TASK 4096
#define COMMAND_BUFFER_SIZE 256
#define RESPONSE_BUFFER_SIZE 512
#define SENSOR_DATA_BUFFER_SIZE 128
#define FIRMWARE_VERSION "1.2.0"
#define FIRMWARE_BUILD_DATE __DATE__ " " __TIME__
#define PROJECT_NAME "R6 Recon Drone"
#define AUTHOR "Peter"
#if !defined(ESP32S3)
#error "This firmware is designed for ESP32-S3 only"
#endif
#if PSRAM_SIZE_MB < 8
#warning "Insufficient PSRAM for optimal camera performance"
#endif
#if FLASH_SIZE_MB < 16
#warning "Limited flash storage may affect OTA and web assets"
#endif
#define ARRAY_SIZE(arr) (sizeof(arr) / sizeof((arr)[0]))
#define PIN_VALID(pin) ((pin) >= 0 && (pin) <= 48)
#define CONSTRAIN(val, min, max) ((val) < (min) ? (min) : ((val) > (max) ? (max) : (val)))
#define MAP_VALUE(x, in_min, in_max, out_min, out_max) \
    ((x - in_min) * (out_max - out_min) / (in_max - in_min) + out_min)
#if DEBUG_ENABLED
#define DEBUG_PRINT(x) Serial.print(x)
#define DEBUG_PRINTLN(x) Serial.println(x)
#define DEBUG_PRINTF(fmt, ...) Serial.printf(fmt, __VA_ARGS__)
#else
#define DEBUG_PRINT(x)
#define DEBUG_PRINTLN(x)
#define DEBUG_PRINTF(fmt, ...)
#endif

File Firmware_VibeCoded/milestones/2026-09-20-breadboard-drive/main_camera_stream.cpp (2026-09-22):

/**
 * @file main_camera_stream.cpp
 * @brief R6 Drone - camera + LED/IMU + hold-to-drive motors
 *
 * MILESTONE LOCK (2026-09-20): working camera, IMU, LED, spotlight,
 * hold-to-drive motors, encoder readout. Do not use this file as a
 * scratch pad; branch or copy before large changes.
 *
 * GPIO (TTL USB-C / CH340 only — do not plug OTG USB-C):
 *   IMU SDA=1 SCL=2 | LED DIN=3 | spotlight=38
 *   Motor A 41/42 | Motor B 39/40 | Left enc 19/20 | Right enc 21/47
 *   Camera DVP 4,5,6,7,8,9,10,11,12,13,15,16,17,18
 *
 * Hold-to-drive only. PID self-balance is intentionally disabled.
 * One physical motor was confirmed faulty on the breadboard; firmware
 * drives both channels.
 */

#include <Arduino.h>
#include <WiFi.h>
#include <WebServer.h>
#include <Adafruit_NeoPixel.h>
#include <Wire.h>
#include "esp_camera.h"
#include "driver/gpio.h"
#include "config.h"
#include "SparkFun_BMI270_Arduino_Library.h"

WebServer server(80);
Adafruit_NeoPixel strip(LED_COUNT, LED_DATA_PIN, LED_TYPE + NEO_KHZ800);
BMI270 imu;

static const size_t MAX_JPEG = 48 * 1024;
static const int8_t QUAD_TABLE[16] = {
    0, -1, 1, 0, 1, 0, 0, -1, -1, 0, 0, 1, 0, 1, -1, 0
};

bool imuInitialized = false;
volatile float pitch = 0.0, roll = 0.0, yaw = 0.0;
float gyroOffsetX = 0.0, gyroOffsetY = 0.0, gyroOffsetZ = 0.0;

bool ledEnabled = true;
uint32_t lastLedUpdate = 0;
int ledAnimationStep = 0;
uint8_t ledR = 0, ledG = 64, ledB = 0;

bool spotlightEnabled = false;
int spotlightBrightness = 128;
bool cameraInitialized = false;
bool motorsInitialized = false;
bool encodersInitialized = false;

volatile char driveCmd = 's';
volatile uint32_t lastDriveMs = 0;
volatile int16_t appliedLeft = 0;
volatile int16_t appliedRight = 0;

volatile int32_t encLeft = 0;
volatile int32_t encRight = 0;
volatile uint8_t encLeftPrev = 0;
volatile uint8_t encRightPrev = 0;

uint8_t *jpegBuf[2] = {nullptr, nullptr};
uint8_t *sendBuf = nullptr;
volatile size_t jpegLen[2] = {0, 0};
volatile int jpegReady = 0;
SemaphoreHandle_t jpegMutex;

void IRAM_ATTR leftEncoderISR() {
    uint8_t curr = (uint8_t)((digitalRead(ENCODER_LEFT_A_PIN) << 1) | digitalRead(ENCODER_LEFT_B_PIN));
    uint8_t idx = (uint8_t)((encLeftPrev << 2) | curr);
    encLeftPrev = curr;
    encLeft += QUAD_TABLE[idx & 0x0F];
}

void IRAM_ATTR rightEncoderISR() {
    uint8_t curr = (uint8_t)((digitalRead(ENCODER_RIGHT_A_PIN) << 1) | digitalRead(ENCODER_RIGHT_B_PIN));
    uint8_t idx = (uint8_t)((encRightPrev << 2) | curr);
    encRightPrev = curr;
    encRight += QUAD_TABLE[idx & 0x0F];
}

static void motorPinLow(uint8_t pin) {
    ledcDetachPin(pin);
    pinMode(pin, OUTPUT);
    digitalWrite(pin, LOW);
}

static void motorPinPwm(uint8_t pin, uint8_t channel, int duty) {
    if (duty < 0) {
        duty = 0;
    }
    if (duty > MOTOR_MAX_SPEED) {
        duty = MOTOR_MAX_SPEED;
    }
    ledcAttachPin(pin, channel);
    ledcWrite(channel, (uint32_t)duty);
}

static void writeOneMotor(uint8_t pinFwd, uint8_t chFwd, uint8_t pinRev, uint8_t chRev, int speed, int *lastSpeed) {
    if (speed > MOTOR_MAX_SPEED) {
        speed = MOTOR_MAX_SPEED;
    } else if (speed < -MOTOR_MAX_SPEED) {
        speed = -MOTOR_MAX_SPEED;
    }

    int sign = (speed > MOTOR_DEADBAND) ? 1 : (speed < -MOTOR_DEADBAND) ? -1 : 0;
    int lastSign = (*lastSpeed > MOTOR_DEADBAND) ? 1 : (*lastSpeed < -MOTOR_DEADBAND) ? -1 : 0;

    if (sign != lastSign) {
        if (sign > 0) {
            motorPinLow(pinRev);
            motorPinPwm(pinFwd, chFwd, speed);
        } else if (sign < 0) {
            motorPinLow(pinFwd);
            motorPinPwm(pinRev, chRev, -speed);
        } else {
            motorPinLow(pinFwd);
            motorPinLow(pinRev);
        }
    } else if (sign > 0) {
        ledcWrite(chFwd, (uint32_t)speed);
    } else if (sign < 0) {
        ledcWrite(chRev, (uint32_t)(-speed));
    }

    *lastSpeed = speed;
}

static void applyDrive() {
    if (!motorsInitialized) {
        return;
    }

    char cmd = driveCmd;
    uint32_t age = millis() - lastDriveMs;
    if (cmd != 's' && age > DRIVE_HOLD_TIMEOUT_MS) {
        cmd = 's';
        driveCmd = 's';
    }

    int left = 0;
    int right = 0;
    switch (cmd) {
        case 'f':
            left = SPEED_FORWARD;
            right = SPEED_FORWARD;
            break;
        case 'b':
            left = -SPEED_BACKWARD;
            right = -SPEED_BACKWARD;
            break;
        case 'l':
            left = -SPEED_TURN_LEFT;
            right = SPEED_TURN_LEFT;
            break;
        case 'r':
            left = SPEED_TURN_RIGHT;
            right = -SPEED_TURN_RIGHT;
            break;
        default:
            left = 0;
            right = 0;
            break;
    }

    static int lastLeft = 0;
    static int lastRight = 0;
    int prevLeft = lastLeft;
    int prevRight = lastRight;
    appliedLeft = (int16_t)left;
    appliedRight = (int16_t)right;
    writeOneMotor(MOTOR_A_PIN1, MOTOR_PWM_CHANNEL_A1, MOTOR_A_PIN2, MOTOR_PWM_CHANNEL_A2, left, &lastLeft);
    writeOneMotor(MOTOR_B_PIN1, MOTOR_PWM_CHANNEL_B1, MOTOR_B_PIN2, MOTOR_PWM_CHANNEL_B2, right, &lastRight);
    if (left != prevLeft || right != prevRight) {
        Serial.printf("PWM L=%d R=%d\n", left, right);
    }
}

static void updateLedsAndImu() {
    uint32_t now = millis();

    if (imuInitialized) {
        static uint32_t lastImu = 0;
        if (now - lastImu >= 15) {
            float dt = (now - lastImu) / 1000.0f;
            lastImu = now;
            if (dt > 0.05f) {
                dt = 0.05f;
            }
            if (imu.getSensorData() == BMI2_OK) {
                float ax = imu.data.accelX;
                float ay = imu.data.accelY;
                float az = imu.data.accelZ;
                float gx = imu.data.gyroX - gyroOffsetX;
                float gy = imu.data.gyroY - gyroOffsetY;
                float gz = imu.data.gyroZ - gyroOffsetZ;
                float accelPitch = atan2(ay, sqrt(ax * ax + az * az)) * 180.0f / PI;
                float accelRoll = atan2(-ax, sqrt(ay * ay + az * az)) * 180.0f / PI;
                pitch = 0.98f * (pitch + gx * dt) + 0.02f * accelPitch;
                roll = 0.98f * (roll + gy * dt) + 0.02f * accelRoll;
                yaw += gz * dt;
            }
        }
    }

    if (ledEnabled && (now - lastLedUpdate >= LED_ANIMATION_SPEED)) {
        lastLedUpdate = now;
        strip.clear();
        switch (ledAnimationStep) {
            case 0:
                break;
            case 1:
            case 5:
                strip.setPixelColor(2, strip.Color(ledR, ledG, ledB));
                strip.setPixelColor(3, strip.Color(ledR, ledG, ledB));
                break;
            case 2:
            case 4:
                for (int i = 1; i <= 4; i++) {
                    strip.setPixelColor(i, strip.Color(ledR, ledG, ledB));
                }
                break;
            case 3:
                for (int i = 0; i < LED_COUNT; i++) {
                    strip.setPixelColor(i, strip.Color(ledR, ledG, ledB));
                }
                break;
        }
        strip.show();
        ledAnimationStep = (ledAnimationStep + 1) % 6;
    }

    ledcWrite(SPOTLIGHT_PWM_CHANNEL, spotlightEnabled ? spotlightBrightness : 0);
    applyDrive();
}

void ledImuTask(void *param) {
    (void)param;
    for (;;) {
        updateLedsAndImu();
        vTaskDelay(pdMS_TO_TICKS(5));
    }
}

void cameraTask(void *param) {
    (void)param;
    int writeIdx = 1;
    for (;;) {
        if (!cameraInitialized) {
            vTaskDelay(pdMS_TO_TICKS(100));
            continue;
        }

        camera_fb_t *fb = esp_camera_fb_get();
        if (fb) {
            if (fb->len > 0 && fb->len <= MAX_JPEG && jpegBuf[writeIdx]) {
                if (xSemaphoreTake(jpegMutex, pdMS_TO_TICKS(5)) == pdTRUE) {
                    memcpy(jpegBuf[writeIdx], fb->buf, fb->len);
                    jpegLen[writeIdx] = fb->len;
                    jpegReady = writeIdx;
                    writeIdx ^= 1;
                    xSemaphoreGive(jpegMutex);
                }
            }
            esp_camera_fb_return(fb);
        }
        vTaskDelay(pdMS_TO_TICKS(50));  // ~20 captures/s, always overwrite old
    }
}

bool initializeCamera() {
    camera_config_t config;
    config.ledc_channel = LEDC_CHANNEL_0;
    config.ledc_timer = LEDC_TIMER_0;
    config.pin_d0 = CAM_PIN_D0;
    config.pin_d1 = CAM_PIN_D1;
    config.pin_d2 = CAM_PIN_D2;
    config.pin_d3 = CAM_PIN_D3;
    config.pin_d4 = CAM_PIN_D4;
    config.pin_d5 = CAM_PIN_D5;
    config.pin_d6 = CAM_PIN_D6;
    config.pin_d7 = CAM_PIN_D7;
    config.pin_xclk = CAM_PIN_XCLK;
    config.pin_pclk = CAM_PIN_PCLK;
    config.pin_vsync = CAM_PIN_VSYNC;
    config.pin_href = CAM_PIN_HREF;
    config.pin_sccb_sda = CAM_PIN_SIOD;
    config.pin_sccb_scl = CAM_PIN_SIOC;
    config.pin_pwdn = -1;
    config.pin_reset = -1;
    config.xclk_freq_hz = 20000000;
    config.pixel_format = PIXFORMAT_JPEG;
    config.frame_size = FRAMESIZE_HVGA;  // 480x320 — small enough to send quickly
    config.jpeg_quality = 22;
    config.fb_count = 2;
    config.grab_mode = CAMERA_GRAB_LATEST;
    config.fb_location = CAMERA_FB_IN_PSRAM;

    if (esp_camera_init(&config) != ESP_OK) {
        Serial.println("Camera init failed");
        return false;
    }

    sensor_t *s = esp_camera_sensor_get();
    if (s) {
        s->set_whitebal(s, 0);
        s->set_awb_gain(s, 0);
        s->set_exposure_ctrl(s, 0);
        s->set_aec2(s, 0);
        s->set_gain_ctrl(s, 0);
        s->set_aec_value(s, 400);
        s->set_agc_gain(s, 8);
        s->set_lenc(s, 1);
        s->set_wpc(s, 1);
        s->set_raw_gma(s, 1);
        s->set_hmirror(s, 0);
        s->set_vflip(s, 0);
        s->set_colorbar(s, 0);
    }
    return true;
}

void handleJpg() {
    if (!jpegBuf[0] || jpegLen[jpegReady] == 0) {
        server.send(503, "text/plain", "no frame");
        return;
    }

    size_t len = 0;
    if (!sendBuf || xSemaphoreTake(jpegMutex, pdMS_TO_TICKS(20)) != pdTRUE) {
        server.send(503, "text/plain", "busy");
        return;
    }
    int idx = jpegReady;
    len = jpegLen[idx];
    if (len > MAX_JPEG) {
        len = MAX_JPEG;
    }
    memcpy(sendBuf, jpegBuf[idx], len);
    xSemaphoreGive(jpegMutex);

    server.sendHeader("Cache-Control", "no-store");
    server.send_P(200, "image/jpeg", (PGM_P)sendBuf, len);
}

bool initializeIMU() {
    Wire.begin(IMU_SDA_PIN, IMU_SCL_PIN);
    Wire.setClock(400000);
    delay(100);

    if (imu.beginI2C(0x69) != BMI2_OK && imu.beginI2C(0x68) != BMI2_OK) {
        Serial.println("BMI270 init failed");
        return false;
    }

    float sx = 0, sy = 0, sz = 0;
    int n = 0;
    for (int i = 0; i < 50; i++) {
        if (imu.getSensorData() == BMI2_OK) {
            sx += imu.data.gyroX;
            sy += imu.data.gyroY;
            sz += imu.data.gyroZ;
            n++;
        }
        delay(10);
    }
    if (n > 0) {
        gyroOffsetX = sx / n;
        gyroOffsetY = sy / n;
        gyroOffsetZ = sz / n;
    }
    Serial.printf("IMU calibrated: %.2f, %.2f, %.2f\n", gyroOffsetX, gyroOffsetY, gyroOffsetZ);
    return true;
}

void initializeSpotlight() {
    ledcSetup(SPOTLIGHT_PWM_CHANNEL, SPOTLIGHT_PWM_FREQ, SPOTLIGHT_PWM_RESOLUTION);
    ledcAttachPin(SPOTLIGHT_PIN, SPOTLIGHT_PWM_CHANNEL);
    ledcWrite(SPOTLIGHT_PWM_CHANNEL, 0);
}

bool initializeMotors() {
    const int pins[] = {MOTOR_A_PIN1, MOTOR_A_PIN2, MOTOR_B_PIN1, MOTOR_B_PIN2};
    for (int i = 0; i < 4; i++) {
        gpio_reset_pin((gpio_num_t)pins[i]);
        pinMode(pins[i], OUTPUT);
        digitalWrite(pins[i], LOW);
    }

    if (!ledcSetup(MOTOR_PWM_CHANNEL_A1, MOTOR_PWM_FREQ, MOTOR_PWM_RESOLUTION) ||
        !ledcSetup(MOTOR_PWM_CHANNEL_A2, MOTOR_PWM_FREQ, MOTOR_PWM_RESOLUTION) ||
        !ledcSetup(MOTOR_PWM_CHANNEL_B1, MOTOR_PWM_FREQ, MOTOR_PWM_RESOLUTION) ||
        !ledcSetup(MOTOR_PWM_CHANNEL_B2, MOTOR_PWM_FREQ, MOTOR_PWM_RESOLUTION)) {
        Serial.println("Motor PWM setup failed");
        return false;
    }

    motorsInitialized = true;
    Serial.printf("Motors ready A=%d/%d B=%d/%d (LEDC %d,%d,%d,%d @ %dHz, idle LOW)\n",
                  MOTOR_A_PIN1, MOTOR_A_PIN2, MOTOR_B_PIN1, MOTOR_B_PIN2,
                  MOTOR_PWM_CHANNEL_A1, MOTOR_PWM_CHANNEL_A2,
                  MOTOR_PWM_CHANNEL_B1, MOTOR_PWM_CHANNEL_B2,
                  MOTOR_PWM_FREQ);
    return true;
}

bool initializeEncoders() {
    pinMode(ENCODER_LEFT_A_PIN, INPUT_PULLUP);
    pinMode(ENCODER_LEFT_B_PIN, INPUT_PULLUP);
    pinMode(ENCODER_RIGHT_A_PIN, INPUT_PULLUP);
    pinMode(ENCODER_RIGHT_B_PIN, INPUT_PULLUP);

    encLeftPrev = (uint8_t)((digitalRead(ENCODER_LEFT_A_PIN) << 1) | digitalRead(ENCODER_LEFT_B_PIN));
    encRightPrev = (uint8_t)((digitalRead(ENCODER_RIGHT_A_PIN) << 1) | digitalRead(ENCODER_RIGHT_B_PIN));
    encLeft = 0;
    encRight = 0;

    attachInterrupt(digitalPinToInterrupt(ENCODER_LEFT_A_PIN), leftEncoderISR, CHANGE);
    attachInterrupt(digitalPinToInterrupt(ENCODER_LEFT_B_PIN), leftEncoderISR, CHANGE);
    attachInterrupt(digitalPinToInterrupt(ENCODER_RIGHT_A_PIN), rightEncoderISR, CHANGE);
    attachInterrupt(digitalPinToInterrupt(ENCODER_RIGHT_B_PIN), rightEncoderISR, CHANGE);

    encodersInitialized = true;
    Serial.printf("Encoders ready L=%d/%d R=%d/%d (TTL USB only, no OTG)\n",
                  ENCODER_LEFT_A_PIN, ENCODER_LEFT_B_PIN,
                  ENCODER_RIGHT_A_PIN, ENCODER_RIGHT_B_PIN);
    return true;
}

static void setDrive(char c, const char *label) {
    if (c != 'f' && c != 'b' && c != 'l' && c != 'r' && c != 's') {
        c = 's';
    }
    driveCmd = c;
    lastDriveMs = millis();
    Serial.printf("DRIVE %s\n", label);
    server.send(200, "text/plain", label);
}

static void setDriveFromRequest() {
    char c = 's';
    if (server.hasArg("d") && server.arg("d").length() > 0) {
        c = server.arg("d").charAt(0);
    }
    const char *label = (c == 'f') ? "FWD" : (c == 'b') ? "BACK" : (c == 'l') ? "LEFT" : (c == 'r') ? "RIGHT" : "STOP";
    setDrive(c, label);
}

void setupWebServer() {
    server.on("/", []() {
        server.sendHeader("Cache-Control", "no-store");
        server.send(200, "text/html",
            "<!DOCTYPE html><html><head><title>R6 Drone</title>"
            "<meta name='viewport' content='width=device-width,initial-scale=1'>"
            "<style>"
            "body{font-family:Arial;margin:16px;background:#111;color:#fff}"
            "h1{color:#ff8c00;text-align:center}"
            ".video{width:100%;max-width:800px;aspect-ratio:16/9;object-fit:cover;"
            "border:2px solid #ff8c00;border-radius:8px;background:#000}"
            ".controls{text-align:center;margin:16px}"
            ".btn{background:#ff8c00;color:#000;border:none;padding:12px 20px;margin:6px;border-radius:6px;font-weight:bold}"
            ".data{color:#4CAF50;font-weight:bold}"
            ".color-row{text-align:center;margin:12px auto;max-width:360px}"
            ".color-row input[type=color]{width:64px;height:36px;border:0;padding:0;background:none;vertical-align:middle}"
            ".rgb{margin-top:8px;color:#ccc;font-size:14px}"
            ".pad{display:grid;grid-template-columns:72px 72px 72px;gap:8px;justify-content:center;margin:18px auto}"
            ".pad .btn{width:72px;height:56px;padding:0;user-select:none;touch-action:none}"
            ".hint{text-align:center;color:#888;font-size:13px;margin-top:4px}"
            "</style></head><body>"
            "<h1>R6 Recon Drone</h1>"
            "<div style='text-align:center'><img id='cam' class='video' alt='camera'></div>"
            "<div class='pad'>"
            "<span></span>"
            "<button type='button' class='btn' id='bf'>FWD</button>"
            "<span></span>"
            "<button type='button' class='btn' id='bl'>LEFT</button>"
            "<button type='button' class='btn' id='bs'>STOP</button>"
            "<button type='button' class='btn' id='br'>RIGHT</button>"
            "<span></span>"
            "<button type='button' class='btn' id='bb'>BACK</button>"
            "<span></span>"
            "</div>"
            "<div class='hint'>Tap FWD for 0.8s spin, or hold. WASD / arrows also work. Tilt does not drive yet.</div>"
            "<div class='controls'>"
            "<button class='btn' onclick=\"fetch('/led/toggle')\">Toggle LEDs</button>"
            "<button class='btn' onclick=\"fetch('/spot/toggle')\">Toggle Spotlight</button>"
            "</div>"
            "<div class='color-row'>"
            "<label>LED color "
            "<input id='ledcol' type='color' value='#004000' oninput='setLedColor(this.value)'>"
            "</label>"
            "<div class='rgb'>R <span id='cr'>0</span> &nbsp; G <span id='cg'>64</span> &nbsp; B <span id='cb'>0</span></div>"
            "</div>"
            "<div style='text-align:center'>"
            "Pitch <span class='data' id='p'>--</span> | "
            "Roll <span class='data' id='r'>--</span> | "
            "Yaw <span class='data' id='y'>--</span><br>"
            "Enc L <span class='data' id='el'>--</span> | "
            "Enc R <span class='data' id='er'>--</span> | "
            "Drive <span class='data' id='drv'>stop</span>"
            "</div>"
            "<script>"
            "var cam=document.getElementById('cam'), oldUrl=null, busy=false;"
            "var holdTimer=null,holdCmd='s',holding=false,holdStart=0;"
            "function frame(){"
            "if(busy||holding){if(holding){setTimeout(frame,80);}return;}"
            "busy=true;"
            "fetch('/jpg',{cache:'no-store'}).then(function(r){"
            "if(!r.ok){throw new Error('jpg');}"
            "return r.blob();"
            "}).then(function(b){"
            "var url=URL.createObjectURL(b);"
            "cam.src=url;"
            "if(oldUrl){URL.revokeObjectURL(oldUrl);}"
            "oldUrl=url;"
            "}).catch(function(){}"
            ").finally(function(){busy=false;setTimeout(frame,50);});"
            "}"
            "function status(){"
            "fetch('/status',{cache:'no-store'}).then(function(r){return r.json();}).then(function(d){"
            "document.getElementById('p').textContent=d.pitch.toFixed(1)+'\\u00b0';"
            "document.getElementById('r').textContent=d.roll.toFixed(1)+'\\u00b0';"
            "document.getElementById('y').textContent=d.yaw.toFixed(1)+'\\u00b0';"
            "document.getElementById('el').textContent=d.encL;"
            "document.getElementById('er').textContent=d.encR;"
            "document.getElementById('drv').textContent=d.drive;"
            "}).catch(function(){});"
            "}"
            "function drive(d){fetch('/'+d,{cache:'no-store'});}"
            "function startHold(cmd){"
            "holding=true;holdCmd=cmd;holdStart=Date.now();drive(cmd);"
            "if(holdTimer){clearInterval(holdTimer);}"
            "holdTimer=setInterval(function(){drive(holdCmd);},150);"
            "}"
            "function stopHold(){"
            "var cmd=holdCmd;"
            "var dur=Date.now()-holdStart;"
            "holding=false;"
            "if(holdTimer){clearInterval(holdTimer);holdTimer=null;}"
            "holdCmd='s';"
            "if(cmd!=='s' && dur<300){drive(cmd);}else{drive('stop');}"
            "}"
            "function bindHold(id,cmd){"
            "var el=document.getElementById(id);"
            "el.onmousedown=function(e){e.preventDefault();startHold(cmd);};"
            "el.onmouseup=function(e){e.preventDefault();stopHold();};"
            "el.ontouchstart=function(e){e.preventDefault();startHold(cmd);};"
            "el.ontouchend=function(e){e.preventDefault();stopHold();};"
            "}"
            "bindHold('bf','fwd');bindHold('bb','back');bindHold('bl','left');bindHold('br','right');"
            "document.getElementById('bs').onclick=function(){stopHold();};"
            "window.onmouseup=function(){if(holding)stopHold();};"
            "var keys={w:'fwd',a:'left',s:'back',d:'right',ArrowUp:'fwd',ArrowLeft:'left',ArrowDown:'back',ArrowRight:'right'};"
            "window.addEventListener('keydown',function(e){"
            "if(e.repeat)return;"
            "var c=keys[e.key];"
            "if(c){e.preventDefault();startHold(c);}"
            "});"
            "window.addEventListener('keyup',function(e){"
            "if(keys[e.key]){e.preventDefault();stopHold();}"
            "});"
            "window.addEventListener('blur',function(){stopHold();});"
            "var colorTimer=null;"
            "function setLedColor(hex){"
            "var r=parseInt(hex.substr(1,2),16);"
            "var g=parseInt(hex.substr(3,2),16);"
            "var b=parseInt(hex.substr(5,2),16);"
            "document.getElementById('cr').textContent=r;"
            "document.getElementById('cg').textContent=g;"
            "document.getElementById('cb').textContent=b;"
            "clearTimeout(colorTimer);"
            "colorTimer=setTimeout(function(){"
            "fetch('/led/color?r='+r+'&g='+g+'&b='+b);"
            "},80);"
            "}"
            "frame();"
            "setInterval(status,200);"
            "status();"
            "</script></body></html>");
    });

    server.on("/jpg", handleJpg);
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
void loop() {
    server.handleClient();

    static uint32_t lastStatus = 0;
    if (millis() - lastStatus > 5000) {
        lastStatus = millis();
        Serial.printf("[%ds] Mem:%dKB frame:%uB IMU:%s Cam:%s LED:%s Mot:%s Enc L/R:%ld/%ld Drive:%c\n",
                      millis() / 1000,
                      ESP.getFreeHeap() / 1024,
                      (unsigned)jpegLen[jpegReady],
                      imuInitialized ? "ON" : "OFF",
                      cameraInitialized ? "ON" : "OFF",
                      ledEnabled ? "ON" : "OFF",
                      motorsInitialized ? "ON" : "OFF",
                      (long)encLeft, (long)encRight,
                      driveCmd);
    }
    delay(1);
}

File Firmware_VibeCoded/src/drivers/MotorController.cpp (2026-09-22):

/**
 * @file MotorController.cpp
 * @brief DRV8833 Motor Driver Implementation
 * @author Peter
 */

#include "MotorController.h"

MotorController::MotorController()
    : currentLeftSpeed(0), currentRightSpeed(0),
      targetLeftSpeed(0), targetRightSpeed(0),
      motorsEnabled(false), emergencyStop(false),
      lastCommandTime(0), smoothControlEnabled(true),
      accelerationRate(ACCELERATION_RATE), decelerationRate(DECELERATION_RATE),
      initialized(false) {
}

bool MotorController::begin() {
    DEBUG_PRINTLN("Initializing DRV8833 Motor Controller...");
    
    // Initialize PWM channels for motor control
    pwmChannels[0] = MOTOR_PWM_CHANNEL_A1; // Motor A Forward
    pwmChannels[1] = MOTOR_PWM_CHANNEL_A2; // Motor A Reverse  
    pwmChannels[2] = MOTOR_PWM_CHANNEL_B1; // Motor B Forward
    pwmChannels[3] = MOTOR_PWM_CHANNEL_B2; // Motor B Reverse
    
    // Configure PWM channels
    for (int i = 0; i < 4; i++) {
        if (!ledcSetup(pwmChannels[i], MOTOR_PWM_FREQ, MOTOR_PWM_RESOLUTION)) {
            DEBUG_PRINTF("Failed to setup PWM channel %d\n", pwmChannels[i]);
            return false;
        }
    }
    
    // Attach pins to PWM channels
    ledcAttachPin(MOTOR_A_PIN1, MOTOR_PWM_CHANNEL_A1);
    ledcAttachPin(MOTOR_A_PIN2, MOTOR_PWM_CHANNEL_A2);
    ledcAttachPin(MOTOR_B_PIN1, MOTOR_PWM_CHANNEL_B1);
    ledcAttachPin(MOTOR_B_PIN2, MOTOR_PWM_CHANNEL_B2);
    
    // Initialize all motors to stopped state
    stop();
    
    initialized = true;
    motorsEnabled = true;
    lastCommandTime = millis();
    
    DEBUG_PRINTLN("DRV8833 Motor Controller initialized");
    return true;
}

void MotorController::reset() {
    stop();
    currentLeftSpeed = 0;
    currentRightSpeed = 0;
    targetLeftSpeed = 0;
    targetRightSpeed = 0;
    emergencyStop = false;
    lastCommandTime = millis();
}
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

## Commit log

2026-07-22 Schematics and PCB layout
    [R6DroneElectronics.brd, R6DroneElectronics.sch]
2026-09-21 Update README.md
    added facebook fan page info
2026-09-22 PCB design updated
    updated PCB schematics, design, removed unnecessary files and added BOM
    [BOM.csv, R6DroneElectronics.brd, R6DroneElectronics.sch]
2026-09-22 Drone body models
    Latest version of the drone body model
    [LED difuser.3mf, main bottom.3mf, main top.3mf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]
2026-09-22 Create Firmware_VibeCoded
    Vide coded firmware with Cursor. At the beginning use Claude Sonar 4 model, later changed back to Cursor Grok 4.6
2026-09-22 Add Firmware_VibeCoded with working ESP32-S3 camera, drive, and stand-test PID firmware.
